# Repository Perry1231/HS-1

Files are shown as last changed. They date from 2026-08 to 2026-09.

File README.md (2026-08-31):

# HS-1

# 🦾 HS-1 Kinematic Suit — Real-Time Motion Tracking System








**HS-1 Kinematic Suit** is a hardware-software system designed for real-time spatial orientation tracking of the human upper limb with continuous 3D rendering. The system utilizes a cascaded hardware architecture of **ESP32-C3 SuperMini** microcontrollers paired with high-precision **Bosch BNO055** 9-axis IMU sensors.

---

## 📌 Key Features

* **UART Cascade Data Bus:** Sequential inter-node data transmission eliminating the need for bulky central controllers.
* **Hardware Orientation Calculation:** Direct readout of absolute Euler angles (Pitch, Yaw, Roll) computed onboard by the Bosch BNO055 DSP fusion engine.
* **High Refresh Rate:** Real-time kinematic data stream sent to PC at **50 Hz** (20 ms interval).
* **Lightweight 3D Visualizer:** Python-based 3D scene implemented via **Ursina Engine** featuring non-blocking background JSON parsing.
* **Modular C++ Architecture:** Strictly defined node responsibilities (Master-Clock, Transmit Relay, USB Hub).

---

## 🛠️ Hardware Architecture

The system consists of three sequentially connected kinematic nodes:

```

┌─────────────────┐       UART       ┌──────────────────┐       UART       ┌─────────────────┐       USB       ┌─────────────────┐
│    Hand Node    ├─────────────────►│   Forearm Node   ├─────────────────►│  Shoulder Node  ├────────────────►│   PC / Python   │
│    (Node #1)    │  14 bytes/pkt    │    (Node #2)     │  28 bytes/pkt    │  (Master Hub)   │   JSON Stream   │  3D Visualizer  │
└─────────────────┘                  └──────────────────┘                  └─────────────────┘                 └─────────────────┘

```

### Component Specifications

| Node | Microcontroller | IMU Sensor | IMU Interface | UART RX / TX | Network Role |
| :--- | :--- | :--- | :--- | :--- | :--- |
| **Hand** | ESP32-C3 SuperMini | Bosch BNO055 | I2C (`0x28`) | `-` / `GPIO 4` | Master Clock Generator (50Hz) |
| **Forearm** | ESP32-C3 SuperMini | Bosch BNO055 | I2C (`0x28`) | `GPIO 1` / `GPIO 4` | Data Aggregator & Transmit Relay |
| **Shoulder** | ESP32-C3 SuperMini | Bosch BNO055 | I2C (`0x28`) | `GPIO 1` / `-` | Master Serial Hub to USB CDC |

---

## 📡 Transmission Protocol

### 1. Internal Binary Packet (UART Cascade)

Inter-node communication between ESP32 microcontrollers uses packed binary structures defined in `ArmPackets.h`:

```cpp
struct __attribute__((packed)) SensorData {
    float yaw;        // 4 bytes (Deg)
    float pitch;      // 4 bytes (Deg)
    float roll;       // 4 bytes (Deg)
    uint8_t calibSys; // 1 byte
    uint8_t calibGyro;// 1 byte
};                    // Total: 14 bytes

```

### 2. Final Output JSON Stream (Serial USB)

The Shoulder Hub aggregates all incoming frame packets and outputs a single-line JSON stream to the PC via USB CDC:

```json
{"shoulder":{"p":12.7,"y":223.9,"r":178.4},"forearm":{"p":45.2,"y":190.1,"r":12.0},"hand":{"p":5.1,"y":188.4,"r":2.3}}

```

---

## 💻 Software & 3D Visualization

The visualizer is built on **Ursina Engine** (Python 3.11). Serial communication runs in a dedicated daemon thread (`threading`) to prevent GUI thread blocking and eliminate rendering lag.

```
Project_Root/
├── app.py                     # Main Ursina visualizer script
├── requirements.txt           # Python dependencies
├── Models/                    # 3D CAD meshes (.obj format)
│   ├── shoulder.obj
│   ├── forearm.obj
│   └── hand.obj
└── Firmware/                  # PlatformIO C++ Source Code
    ├── hand/
    ├── forearm/
    └── shoulder/

```

---

## 🚀 Quick Start

```markdown
## 🚀 Quick Start

### 1. Download & Installation

You can clone the repository via Git or download the source code package directly:

#### Option A: Clone via Git (Recommended)
```bash
git clone [https://github.com/Perry132/HS-1-Kinematic-Suit.git](https://github.com/Perry132/HS-1-Kinematic-Suit.git)
cd HS-1-Kinematic-Suit

```

#### Option B: Direct ZIP Download

Download the latest source code archive directly:
[📥 Download HS-1 Kinematic Suit (.zip)](https://www.google.com/search?q=https://github.com/Perry132/HS-1-Kinematic-Suit/archive/refs/heads/main.zip)

---

### 2. Firmware Deployment

Flash each node with its corresponding PlatformIO project located in `Firmware/`:

```bash
# Upload Hand Firmware
platformio run --target upload --project-dir Firmware/hand

# Upload Forearm Firmware
platformio run --target upload --project-dir Firmware/forearm

# Upload Shoulder Firmware
platformio run --target upload --project-dir Firmware/shoulder

```

---

### 3. Python Environment Setup

Install all required dependencies using `requirements.txt`:

```bash
pip install -r requirements.txt

```

---

### 4. Running the Visualizer

Set your active COM port inside `app.py` (`SERIAL_PORT = 'COMx'`) and launch the application:

```bash
python app.py

```

```

<ElicitationsGroup message="Next steps for repo optimization:">
  <Elicitation label="Generate requirements.txt file contents" query="Provide the exact contents for the requirements.txt file for the HS-1 project"/>
  <Elicitation label="Add a Troubleshooting section to README.md" query="Add a comprehensive Troubleshooting section to the English README.md covering UART, COM port, and BNO055 issues"/>
</ElicitationsGroup>

```

### 3. Running the Visualizer

Specify your active COM port inside `app.py` (`SERIAL_PORT = 'COMx'`) and launch:

```bash
python app.py

```

---
## Documentation

[Review HS-1 Documentation](https://github.com/Perry1231/HS-1/blob/main/HS-1%20Short_Documentation.txt)
---

## 👤 Author

**Vladyslav Vytrykush**

* GitHub: [@Perry132](https://www.google.com/search?q=https://github.com/Perry132)
* Specialty: Electronics & Embedded Systems (Lviv Polytechnic National University)

---

*Developed as part of the HS-1 spatial orientation tracking suit project.*

```

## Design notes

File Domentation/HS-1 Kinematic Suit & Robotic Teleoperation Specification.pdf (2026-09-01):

# HS-1 Kinematic Suit & Robotic Teleoperation Platform — Comprehensive Technical Specification

This document presents the complete system architecture, hardware specifications, firmware protocols, 3D visualization setup, and strategic expansion roadmap for the HS-1 Kinematic Motion Tracking Suit and its teleoperation integration with external robotic platforms (such as the DeadGrip X-01 prototype).

## 1. System Architecture & Hardware Specification

### 1.1 Bill of Materials (BOM)

Component | Quantity | Technical Description / Application
ESP32-C3 SuperMini | 14 pcs | Main processing microcontrollers (13 limb sensor nodes + 1 Master Multiplexer Hub).
Adafruit / GY BNO-055 | 13 pcs | 9-DOF IMU absolute orientation fusion sensors.
Silicone Stranded Wire (20 AWG) | 20 meters | Main power backbone (5V VBUS / 3.3V) and shared ground (GND) lines.
Perfboards (5x7 cm) | 14 pcs | Prototyping circuit boards for modular node assembly.

Component | Quantity | Technical Description / Application
Pull-up Resistors | 10 kOhm | Optional line stabilization for I2C communication.
Auxiliary Connectors & Passive Elements | Various | Header pins, 100nF decoupling capacitors, and textile mounts.

### 1.2 Internal Node Pinout Matrix (I2C Protocol)

Each individual limb node pairs a local ESP32-C3 SuperMini with a dedicated BNO-055 sensor over I2C:

Signal Line | ESP32-C3 Pin | BNO-055 Pin | Configuration / Hardware Requirement
SDA | GPIO 3 | SDA / ATX | I2C Serial Data Line
SCL | GPIO 2 | SCL / LRX | I2C Serial Clock Line (100 kHz)
Power (3.3V) | 3V3 | VIN / 3.3V | Regulated 3.3V Power Line
Ground | GND | GND | Common Shared Ground
Protocol Lock 0 | — | PS0 $\rightarrow$ GND | Hardwires BNO-055 into I2C Mode
Protocol Lock 1 | — | PS1 $\rightarrow$ | Hardwires BNO-055

Signal Line | ESP32-C3 Pin | BNO-055 Pin | Configuration / Hardware Requirement
| | GND | into I2C Mode

### 1.3 Inter-Module Cascaded UART Bus

Data packets propagate sequentially along limb channels via hardware UART to prevent bus contention and simplify wiring:
- Hand Node (Node 3): Transmits packet via GPIO 4 (Tx) $\rightarrow$ GPIO 1 (Rx) of Forearm Node.
- Forearm Node (Node 2): Ingests Hand packet, appends local sensor data, and transmits via GPIO 4 (Tx) $\rightarrow$ GPIO 1 (Rx) of Shoulder Node.
- Shoulder Master Node (Node 1): Ingests Forearm/Hand stream, appends Shoulder data, and routes stream via GPIO 4 (Tx) $\rightarrow$ Multiplexer input on the Main ESP32-C3 Hub.
- Host PC Output: USB CDC Serial line-delimited JSON stream at 115200 Baud (~50 Hz refresh rate).

## 2. Firmware Data Structures & Host JSON Protocol

### 2.1 Memory-Aligned Binary Struct (ArmPackets.h)

#ifndef ARM_PACKETS_H

#define ARM_PACKETS_H

#include <stdint.h>

#pragma pack(push, 1)

// Compact 14-byte binary payload for a single IMU node
struct SensorData {
float yaw; | // 4 bytes: Euler Yaw (0.0 to 360.0 deg)
float pitch; | // 4 bytes: Euler Pitch (-180.0 to 180.0 deg)
float roll; | // 4 bytes: Euler Roll (-90.0 to 90.0 deg)
uint8_t calibSys; | // 1 byte: | System calibration status (0 to 3)
uint8_t calibGyro; | // 1 byte: | Gyroscope calibration status (0 to

3)
};

// Cascaded arm segment packet
struct FullArmPacket {
SensorData hand; | // Node 3 (Hand)
SensorData forearm; | // Node 2 (Forearm)
SensorData shoulder; | // Node 1 (Shoulder)
};

#pragma pack(pop)

#endif // ARM_PACKETS_H

### 2.2 Serial JSON Telemetry Output Format

{
"hand": { "y": 12.5, "p": -4.2, "r": 0.1, "c_sys": 3, "c_gyro": 3 }, "forearm": { "y": 45.0, "p": 10.2, "r": -1.5, "c_sys": 3, "c_gyro": 3 },
"shoulder": { "y": 88.1, "p": 120.0, "r": 15.3, "c_sys": 2, "c_gyro": 3 }
}

## 3. 3D Visualizer & CAD Modeling Guidelines

### 3.1 Kinematic Bone Hierarchy (Ursina Engine)

- World Origin Grid (0, 0, 0): Master anchor point.
- Shoulder Entity: Parented to World; updated by Shoulder node rotation ($Y, P, R$).
- Forearm Entity: Parented to Shoulder; offset to the Elbow Pivot Joint.
- Hand Entity: Parented to Forearm; offset to the Wrist Rotational Joint.

### 3.2 Autodesk Fusion 360 Export Rules

1. Mesh Formats: Export isolated body segments as .OBJ files.
2. Pivot Coordinates (0,0,0):
- shoulder.obj: Origin placed directly at the center of the shoulder sphere joint.
- forearm.obj: Origin placed directly on the elbow hinge axis.

- hand.obj: Origin placed directly at the wrist rotational joint center.
3. Axis Orientation: $+Y$ aligned downward along the bone axis; $+Z$ aligned forward.

## 4. Development Roadmap & Teleoperation Milestones

Teleoperation Vision: The HS-1 full-body suit captures live motion telemetry ($\ge 100\text{ Hz}$) to drive external robotic avatars (e.g., DeadGrip X-01) with ultra-low latency.

Phase / Milestone | Key Objectives & Hardware Expansion | Target Version | Status
Phase 1 | Single-arm tracking over UART cascade + Ursina Visualizer. | v1.0.0 | Completed
Phase 2 | • Quaternion stream integration ($W, X, Y, Z$) • Assembly & integration of the Main Processing Hub • Assembly & wiring of the Second Arm to the Main Hub
| • BVH Animation Exporter for Blender/Maya
v1.1.0 | In Progress
Phase 3 | • Assembly & wiring
of Leg Tracking
Modules to the Main
Hub
- Long-Range
Wireless Data
v1.5.0 | Planned

Phase / Milestone Key Objectives & Hardware
Expansion
Target Version | Status

Module (ESP-NOW /
Wi-Fi)
- Initial full-suit
physical textile
assembly & wire
routing
- Start of Robotic
Avatar (DeadGrip
X-01) teleoperation
integration
- Comprehensive
sensor calibration
benchmarking &
stress tests
Phase 4 | • Final 13-Node Full-Body Suit deployment • Custom Power Distribution PCB design • Full-scale robot teleoperation control & dynamic response testing • UE5 / Unity LiveLink Plugins
v2.0.0 | Planned

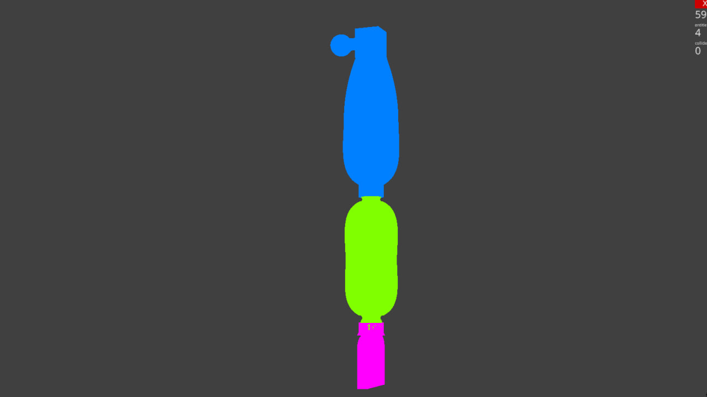
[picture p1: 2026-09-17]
Domentation/Photo/Python_interpretation_2.0.jpg

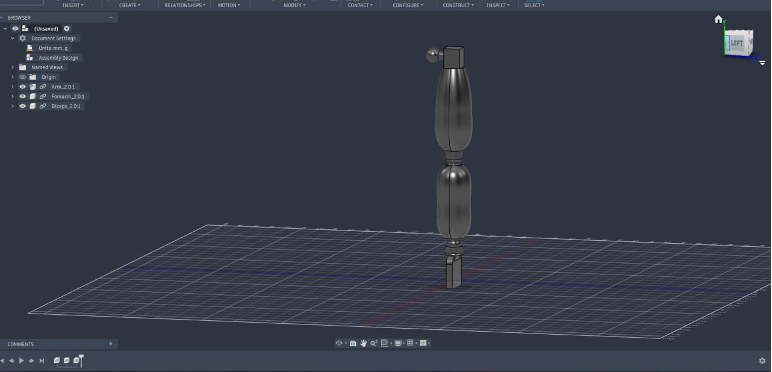
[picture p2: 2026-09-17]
Domentation/Photo/Fusion_model_2.0.jpg

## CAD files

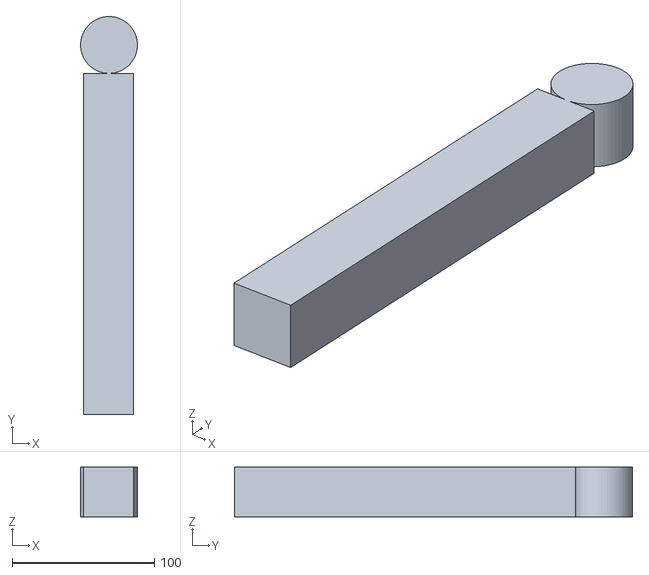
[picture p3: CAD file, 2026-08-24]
Domentation/Models/1.0/Forearm.obj
40.0 x 280.0 x 35.0

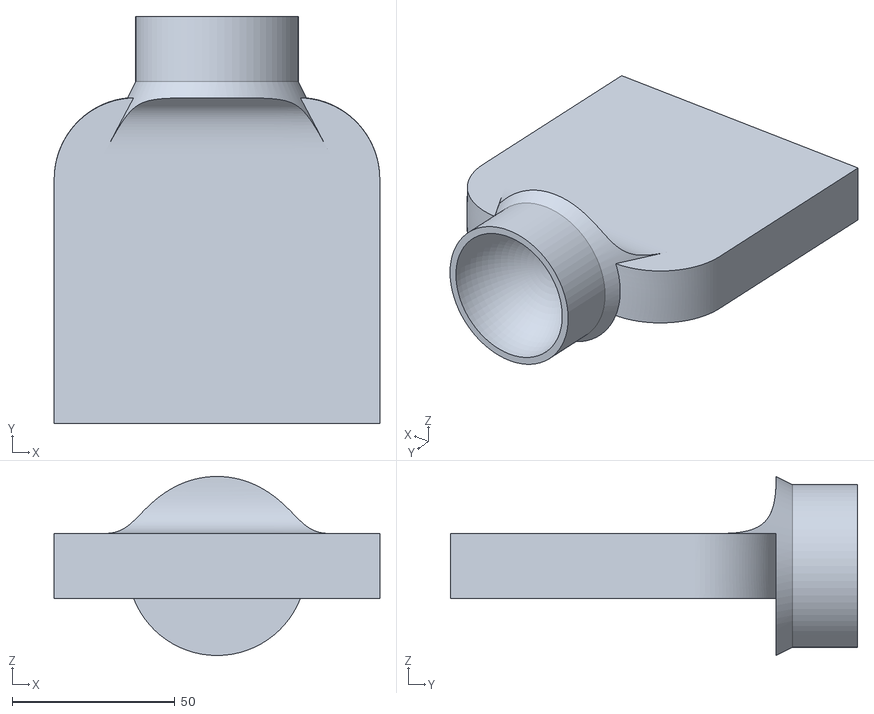
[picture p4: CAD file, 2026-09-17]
Domentation/Models/2.0/Hand_2_0.stl
100.0 x 125.0 x 55.0

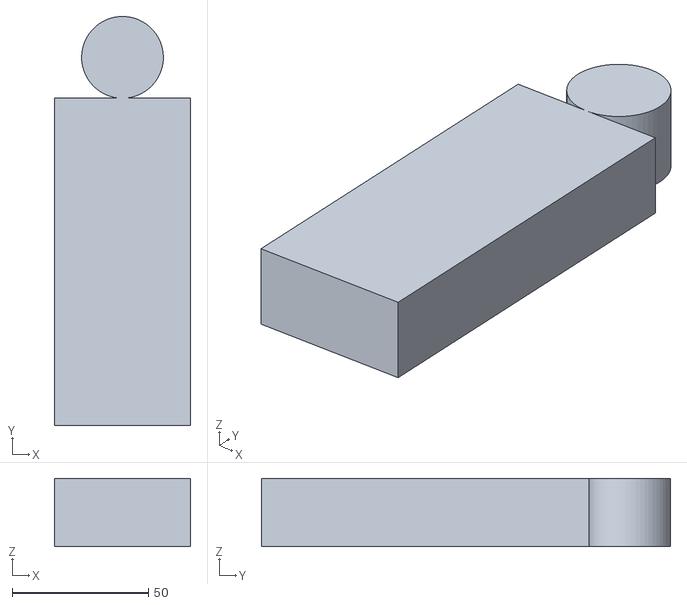
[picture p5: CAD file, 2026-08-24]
Domentation/Models/1.0/Hand.obj
50.0 x 150.0 x 25.0

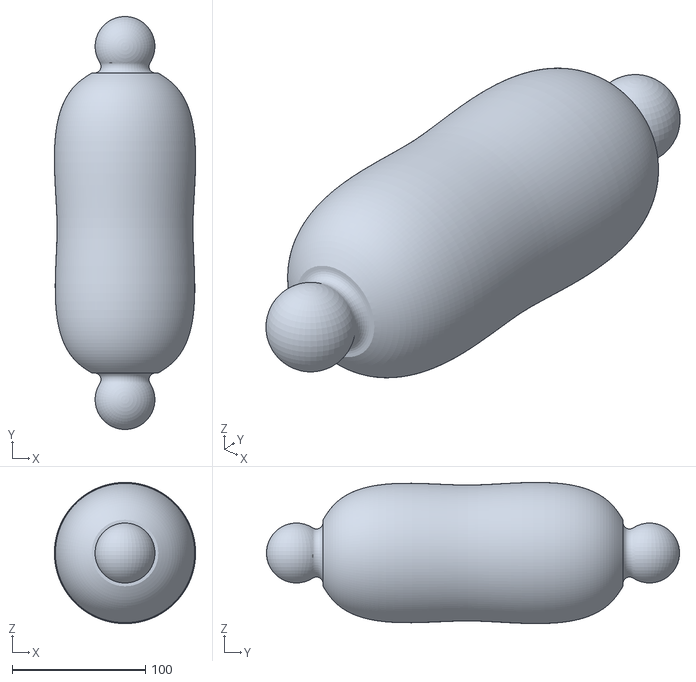
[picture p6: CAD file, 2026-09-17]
Domentation/Models/2.0/Forearm_2_0.stl
106.0 x 309.9 x 105.9

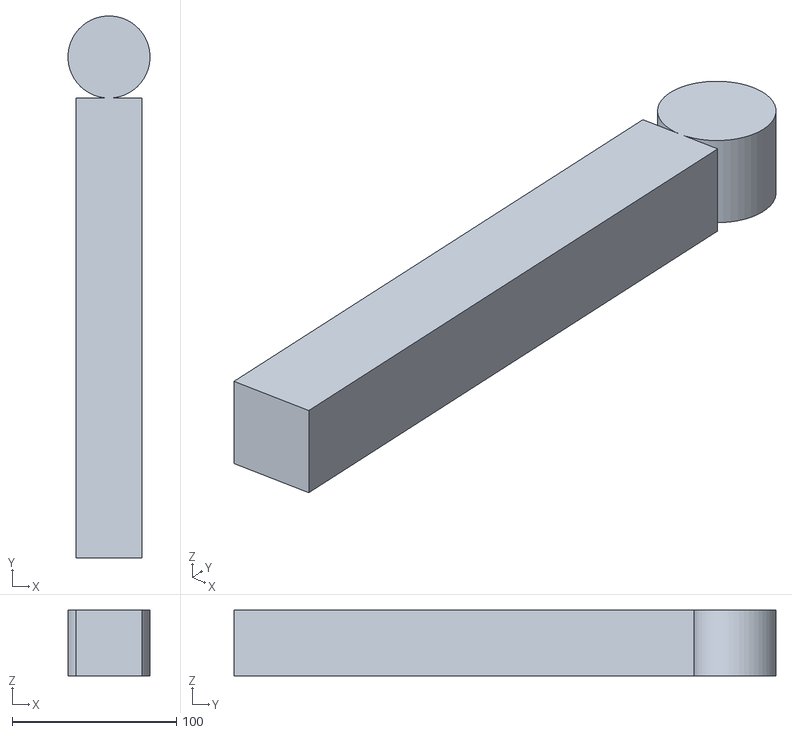
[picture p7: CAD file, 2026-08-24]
Domentation/Models/1.0/Shoulder.obj
50.0 x 329.9 x 40.0

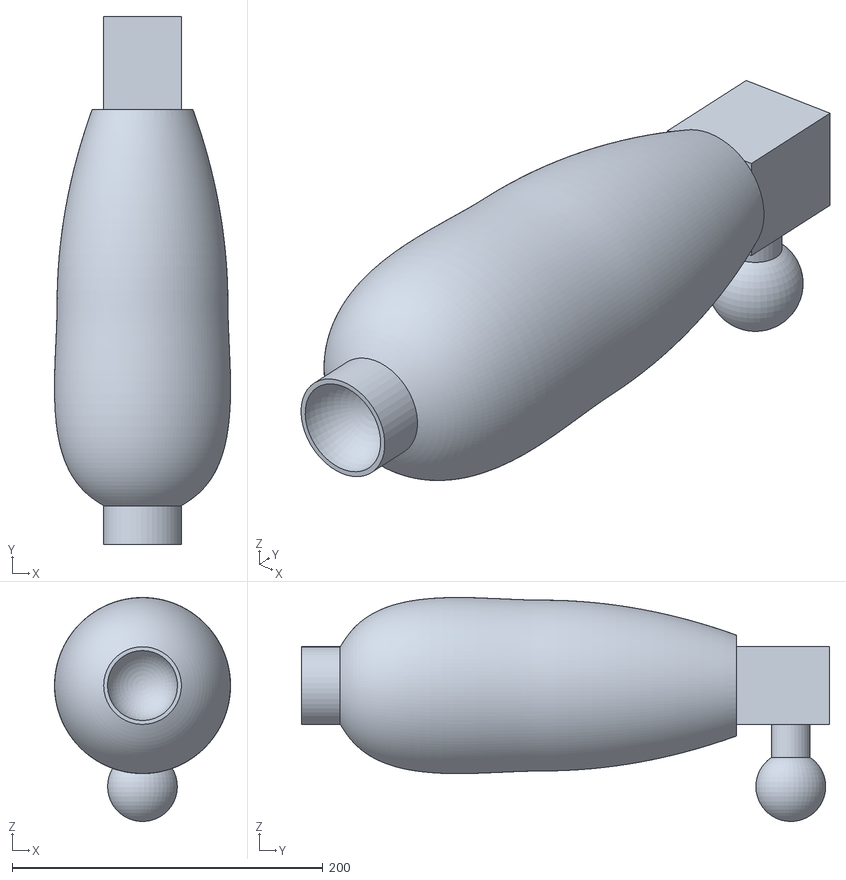
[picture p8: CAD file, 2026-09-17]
Domentation/Models/2.0/Biceps_2_0.stl
113.3 x 340.0 x 144.2

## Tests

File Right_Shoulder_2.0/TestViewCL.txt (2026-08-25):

Test view in command line

```markdown
### 📡 Serial Data Output Format

The Shoulder module aggregates data from the entire HS-1 cascade chain via UART and outputs a structured JSON stream through USB Serial (`115200` baud rate) for real-time Python/Ursina visualization:

```json
{"shoulder":{"p":12.4,"y":102.1,"r":178.5},"forearm":{"p":-5.1,"y":88.3,"r":12.2},"hand":{"p":-2.6,"y":282.9,"r":177.5}}

```

#### **JSON Structure Breakdown:**

| Joint Key | Parameters | Description |
| --- | --- | --- |
| `shoulder` | `p` (Pitch), `y` (Yaw), `r` (Roll) | Orientation angles from Upper Arm BNO055 |
| `forearm` | `p` (Pitch), `y` (Yaw), `r` (Roll) | Orientation angles forwarded from Forearm BNO055 |
| `hand` | `p` (Pitch), `y` (Yaw), `r` (Roll) | Orientation angles passed through from Wrist BNO055 |

> **Note:** All angles are reported in degrees ($-180.0^\circ$ to $+180.0^\circ$ / $0.0^\circ$ to $360.0^\circ$). The update rate of the cascade stream is synchronized to **~50 Hz (20 ms loop interval)**.

```

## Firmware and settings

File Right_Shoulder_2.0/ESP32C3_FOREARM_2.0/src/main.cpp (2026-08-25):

#include <Arduino.h>
#include <Wire.h>
#include <Adafruit_Sensor.h>
#include <Adafruit_BNO055.h>
#include "ArmPackets.h"

#define SDA_PIN 3
#define SCL_PIN 2
#define RX_PIN  1
#define TX_PIN  4

// Створюємо об'єкти під обидві можливі адреси
Adafruit_BNO055 bno28 = Adafruit_BNO055(55, 0x28, &Wire);
Adafruit_BNO055 bno29 = Adafruit_BNO055(55, 0x29, &Wire);

// Вказуємо вказівник на активний сенсор
Adafruit_BNO055* activeBno = nullptr;

HardwareSerial LinkSerial(1);
SensorData handData;
SensorData forearmData;

void setup() {
  LinkSerial.begin(115200, SERIAL_8N1, RX_PIN, TX_PIN);
  pinMode(SDA_PIN, INPUT_PULLUP);
pinMode(SCL_PIN, OUTPUT);

for (int i = 0; i < 10; i++) {
  digitalWrite(SCL_PIN, HIGH);
  delayMicroseconds(5);
  digitalWrite(SCL_PIN, LOW);
  delayMicroseconds(5);
}


  Wire.begin(SDA_PIN, SCL_PIN, 100000);

  // 1. Пробуємо завантажити за адресою 0x28
  if (bno28.begin(OPERATION_MODE_NDOF)) {
    activeBno = &bno28;
    activeBno->setExtCrystalUse(false);
  } 
  // 2. Якщо 0x28 не відповів, пробуємо 0x29
  else if (bno29.begin(OPERATION_MODE_NDOF)) {
    activeBno = &bno29;
    activeBno->setExtCrystalUse(false);
  }
}

void loop() {
  // 1. Зчитуємо пакет від Кисті
  while (LinkSerial.available() >= sizeof(SensorData)) {
    LinkSerial.readBytes((uint8_t*)&handData, sizeof(SensorData));
  }

  // 2. Якщо якийсь із BNO055 підключився — зчитуємо його
  if (activeBno != nullptr) {
    sensors_event_t event;
    activeBno->getEvent(&event);
    forearmData.yaw = event.orientation.x;
    forearmData.pitch = event.orientation.y;
    forearmData.roll = event.orientation.z;
  }

  // 3. Відправляємо каскад (Hand + Forearm) на Плече
  LinkSerial.write((uint8_t*)&handData, sizeof(SensorData));
  LinkSerial.write((uint8_t*)&forearmData, sizeof(SensorData));

  delay(20);
}

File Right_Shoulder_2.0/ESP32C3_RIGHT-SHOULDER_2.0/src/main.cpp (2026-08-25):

#include <Arduino.h>
#include <Wire.h>
#include <Adafruit_Sensor.h>
#include <Adafruit_BNO055.h>
#include "ArmPackets.h"

#define SDA_PIN 3
#define SCL_PIN 2
#define RX_PIN  1

Adafruit_BNO055 bno = Adafruit_BNO055(55, 0x28, &Wire);
HardwareSerial LinkSerial(1);
FullArmPacket fullArm;

void setup() {
  Serial.begin(115200);
  LinkSerial.begin(115200, SERIAL_8N1, RX_PIN, -1);
  // Додати у setup() Плеча та Передпліччя ПЕРЕД Wire.begin()
pinMode(SDA_PIN, INPUT_PULLUP);
pinMode(SCL_PIN, OUTPUT);

for (int i = 0; i < 10; i++) {
  digitalWrite(SCL_PIN, HIGH);
  delayMicroseconds(5);
  digitalWrite(SCL_PIN, LOW);
  delayMicroseconds(5);
}


  Wire.begin(SDA_PIN, SCL_PIN, 100000);
  if (bno.begin(OPERATION_MODE_NDOF)) {
    bno.setExtCrystalUse(false);
  }
}

void loop() {
  // Зчитуємо ровно 24 байти (Hand + Forearm)
  while (LinkSerial.available() >= (sizeof(SensorData) * 2)) {
    LinkSerial.readBytes((uint8_t*)&fullArm.hand, sizeof(SensorData));
    LinkSerial.readBytes((uint8_t*)&fullArm.forearm, sizeof(SensorData));
  }

  // Власний BNO055 Плеча
  sensors_event_t event;
  bno.getEvent(&event);
  fullArm.shoulder.yaw = event.orientation.x;
  fullArm.shoulder.pitch = event.orientation.y;
  fullArm.shoulder.roll = event.orientation.z;

  // Фільтр від сміття
  if (abs(fullArm.hand.roll) < 361.0 && abs(fullArm.forearm.roll) < 361.0) {
    Serial.printf("{\"shoulder\":{\"p\":%.1f,\"y\":%.1f,\"r\":%.1f},\"forearm\":{\"p\":%.1f,\"y\":%.1f,\"r\":%.1f},\"hand\":{\"p\":%.1f,\"y\":%.1f,\"r\":%.1f}}\n",
                  fullArm.shoulder.pitch, fullArm.shoulder.yaw, fullArm.shoulder.roll,
                  fullArm.forearm.pitch, fullArm.forearm.yaw, fullArm.forearm.roll,
                  fullArm.hand.pitch, fullArm.hand.yaw, fullArm.hand.roll);
  }

  delay(20);
}

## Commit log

2026-07-30 Commit 1 (Added new folder for testing shoulder esp32c3 for 1 bno055)
2026-08-02 Commit 3 (Added code for 2 BNO055 1-shoulder , 2 -biceps. I2C-connect)
2026-08-03 Commit 4 (Added KiCad structure of Shoulder_Right module (ESP32-C3 + BNO_055_9DOF))
    [KiCad_resolution.kicad_pcb, KiCad_resolution.kicad_sch]
2026-08-04 Commit 5 (Added PCB file , added BNO_055 library of view)
    [KiCad_resolution.kicad_pcb, KiCad_resolution.kicad_sch]
2026-08-04 Commit 6 (Added new I2C wire for second BNO_055 , checking and testing new code (Problem with wire and pinout connection))
    [main.cpp]
2026-08-04 Commit 7C (Code fix for biceps + shoulder modules)
    [main.cpp]
2026-08-12 Commit 15 (fix)
    [KiCad_resolution.kicad_pcb, KiCad_resolution.kicad_sch]
2026-08-19 Commit 22D (Added files as 3d)
    [Forearm.obj, Hand.obj, Shoulder.obj]
2026-08-19 Commit 23C (Fix app.py for programm)
    [app.py]
2026-08-19 Commit 24C (Added new file to convert mesh from recktangles to triangles)
    [Forearm.obj, Hand.obj, Shoulder.obj]
2026-08-19 Commit 25C (Fix app.py)
    [app.py]
2026-08-19 Commit 26C (Fix app.py , model in proggram view)
    [app.py]
2026-08-19 Commit 27C (Moving arm)
2026-08-24 Commit 28C (Fix ESP32C3_Right-Shoulder_2.0 code for app.py programm)
    [main.cpp]
2026-08-24 Commit 29C (Fixed code in HS-1 programm for start (app.py))
    [app.py]
2026-08-24 Commit 30C (Fixxed code in app.py programm)
    [app.py]
2026-08-24 Commit 30D (Fixed .obj files)
    [Forearm.obj, Hand.obj, Shoulder.obj]
2026-08-24 Commit 31C (Fixed code in Arm , Forearm , Shoulder for right hand (.cpp))
    [main.cpp]
2026-08-25 Commit 32C (Fixed code for Right_Shoulder module)
    [main.cpp]
2026-08-25 (Fixed code for Hand module)
    [main.cpp]
2026-08-25 (Fixed code for RightShoulder module)
    [main.cpp]
2026-09-01 Commit 33D (adjustment of iles in repository | Added wiki | Added short documenattion that will be expanded in future)
    [Forearm.obj, Hand.obj, Shoulder.obj]
2026-09-17 Commit 34D (Added new part *detalized)
    [Arm_2_0.stl, Biceps_2_0.stl, Forearm.obj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]
2026-09-17 Commit 35C (Fixed code and model for Ursina*)
    [Hand_2_0.stl]
2026-09-17 Commit 36D (fixed file , added photos)
    [Biceps_2_0.stl, Forearm.obj, Forearm_2.0.obj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]
2026-10-11 Commit 37D (Added models for legs (3 parts: upper , mid and foot), uploaded them in folder)
2026-10-12 Commit 37_4C (Fixed higher_pivot of leg)
2026-10-13 Commit 37_6C (Fixed right leg position)
2026-10-24 Commit 38_1D (Archived for documentation files of stl -> objects)
2026-11-07 Commit 41_1D (Edit and completed full PCB model)
2026-11-13 Commit 42_3C (Added target frame rate and telemetry com settings to proggram settings page)
2026-11-13 Commit 42_4C (Added UART baud rate + 3D scene overlay + sensor calibration functions to settings page)
2026-11-13 Commit 42_5C (Added camera speed + camera field of viev + motion smoothing settings in proggramm setiings page)

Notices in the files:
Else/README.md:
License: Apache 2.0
